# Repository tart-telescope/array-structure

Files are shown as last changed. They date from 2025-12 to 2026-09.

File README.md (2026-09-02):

# TART Array Structure

CAD files for the mechanical structure of the [TART (Transient Array Radio Telescope)](https://tart.elec.ac.nz/) antenna array — an open-source, low-cost radio telescope built from arrays of small antennas.

This repository contains the full set of design files needed to build the array structure: the master FreeCAD design, flat-pack cutting files (DXF) for CNC machining, 3D-printable parts (STL/3MF), and the FreeCAD source files for each component.

## Repository Layout

```
array-structure/
├── array-design.FCStd          # Master FreeCAD design of the spiral array structure
├── array-design.dxf            # 2D export of the array design
├── array-design.stp            # STEP (3D CAD exchange) export of the array design
├── spiral-array-screenshot.png # Render of the array
├── spiral-array-screenshot-2.png
├── brackets/                   # Brackets for mounting the array arms
├── cam-files/                  # CNC/laser/water-jet cutting files for plywood sheets
├── supports/                   # Stand support structures
└── truss_tube_support/         # Truss-tube support structure (3D-printable)
```

## cam-files/ — Plywood Cutting Files

Files for CNC cutting the flat-pack array structure from sheets of marine-grade exterior plywood. Each file is a full 2400 × 1200 mm sheet, and includes a marked 100 × 100 mm reference square for the workshop to calibrate dimensions against.

| File | Material |
|---|---|
| `tart_array_4mm_sheet_1.dxf` | Full sheet 2400 × 1200 mm, 4–6 mm plywood |
| `tart_array_4mm_sheet_2.dxf` | Full sheet 2400 × 1200 mm, 4–6 mm plywood |
| `tart_array_9mm.dxf` | Full sheet 2400 × 1200 mm, 9–12 mm plywood |

SVG versions are also provided. The sheets can be cut by laser or water-jet (both are unlikely to shift the material during cutting).

## brackets/ — Mounting Brackets

FreeCAD (`*.FCStd`) designs for the brackets that join the array components:

- `centre to post bracket.FCStd` — connects the array centre to the support post
- `post to arm bracket.FCStd` — connects the support post to the array arms
- `post to arm bracket-Post side bracket.3mf` — 3D-printable export of the post-side bracket

## supports/ — Stand Supports

- `StandFoot.FCStd` — stand foot designed for a 30 mm PVC pipe to serve as the stand leg.

## truss_tube_support/ — Truss Tube Support Structure

A truss-tube support structure design by **Shoaib Mirza** (shoaibmirza@iub.edu.bd), Independent University, Bangladesh, developed for the Bangladesh TART installation.

- `STLs/` — 16 3D-printable parts (STL, binary) covering the full assembly:

  | Group | Parts |
  |-------|-------|
  | Center Hub Assembly | `HUB-001` (top), `HUB-002` (middle), `HUB-003` (bottom) |
  | Joint Assembly | `JNT-001` base joint, `JNT-002`/`JNT-003` top joint parts A/B |
  | Stand Leg Assembly | `LEG-001`–`LEG-004` (parts A–D) |
  | Mount Assembly | `MNT-001` wing mount, `MNT-002`/`MNT-003` top secondary mount parts A/B |
  | Wing Assembly | `WNG-001` (top), `WNG-002` (middle), `WNG-003` (bottom) panels |

- `BOM_STL_Export.csv` — bill of materials listing every part, its assembly group, file name and format
- `full_assembly_step/truss_tube_tart.step` — full assembly as a STEP file
- `renders_and_drawings/START_stand_drawing_v4.pdf` — drawing of the stand

## Building Your Own Array

The DXF cutting files for the current array design live in the `cam-files/` directory (see the cam-files [README](cam-files/README.md) for details). All files in this repository are open — download, cut or print, and assemble.

## Videos

Build and installation guides on YouTube for the TART array structure:

| Video | Channel | What it covers |
|---|---|---|
| [The Structure of the TART Spiral Antenna Array](https://www.youtube.com/watch?v=TuFPHJMHvuQ) | TART Radio Telescope | How the spiral array is constructed from 3 layers of flat material, plus mounting it on site — the closest match to the `cam-files/` plywood sheets in this repo |
| [How to Build a Cheap Radio Telescope (TART Single Sheet)](https://www.youtube.com/watch?v=K_8zffsw-ng) | TART Radio Telescope | Full build of the simplest TART version from a single standard-size plywood sheet using off-the-shelf components |
| [Single Sheet Radio Telescope Antenna Array Construction](https://www.youtube.com/watch?v=15vWiKbK2I0) | Elec Research | How to make a simple single-sheet TART antenna array with easily available tools and materials |
| [Installing a Spiral TART Using Wooden Posts](https://www.youtube.com/watch?v=bsTKXGvduMo) | TART Radio Telescope | On-site installation: locating the posts that support each arm and making the final arm assembly — relevant to the `brackets/` and `supports/` designs |
| [Single Sheet TART Antenna Array Optimization](https://www.youtube.com/watch?v=b-6-I6850Wc) | Elec Research | Evolution of the antenna layout constrained to a single sheet of plywood — background on the `cam-files/` design |

More videos, including the "How to Build a Cheap Radio Telescope" series, are on the official [TART Radio Telescope YouTube channel](https://www.youtube.com/@TARTRadioTelescope).

## License / Credits

- Truss-tube support structure: Shoaib Mirza (Independent University, Bangladesh).
- See the `truss_tube_support/README.md` for details.

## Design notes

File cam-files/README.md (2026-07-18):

# Building your own array

There is a github repository (https://github.com/tart-telescope/array-structure) with DXF files for building the current antenna array design. The cam_files directory contains files to be CNC cut from sheets of marine grade experior plywood.

* [tart_array_4mm_sheet_1.dxf](https://github.com/tart-telescope/array-structure/blob/main/cam-files/tart_array_4mm_sheet_1.dxf). To be cut from a full sheet 2400x1200mm 4-6mm thickness plywood.
* [tart_array_4mm_sheet_2.dxf](https://github.com/tart-telescope/array-structure/blob/main/cam-files/tart_array_4mm_sheet_1.dxf). To be cut from a full sheet 2400x1200mm 4-6mm thickness plywood.
* [tart_array_9mm.dxf](https://github.com/tart-telescope/array-structure/blob/main/cam-files/tart_array_9mm.dxf). To be cut from a full sheet 2400x1200mm 9-12mm thickness plywood.

These three sheets can either be laser cut, or water-jet cut (these two options are unlikely to move during cutting). On each sheet is a 100mm x 100mm square (marked as such) that can be used as a reference for dimensions by the workshop doing the cutting.

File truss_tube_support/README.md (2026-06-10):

## Truss Tube Support Structure

By Shoaib Mirza (shoaibmirza@iub.edu.bd)

This beautiful design was developed by Shoaib Mirza of IUB Bangladesh for the Bangladesh TART installation.

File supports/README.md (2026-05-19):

## TART Array Supports

This file contains some standard support structures for the TART array.

### StandFoot

Designed for a 30mm PVC Pipe to act as stand feet.

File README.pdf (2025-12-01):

# TART Spiral Array Instructions to the Fabricator

This document contains instructions to help understand TART design and the DXF file provided with this document.

Written July 2025 – Theo Molteno (theo@elec.ac.nz)

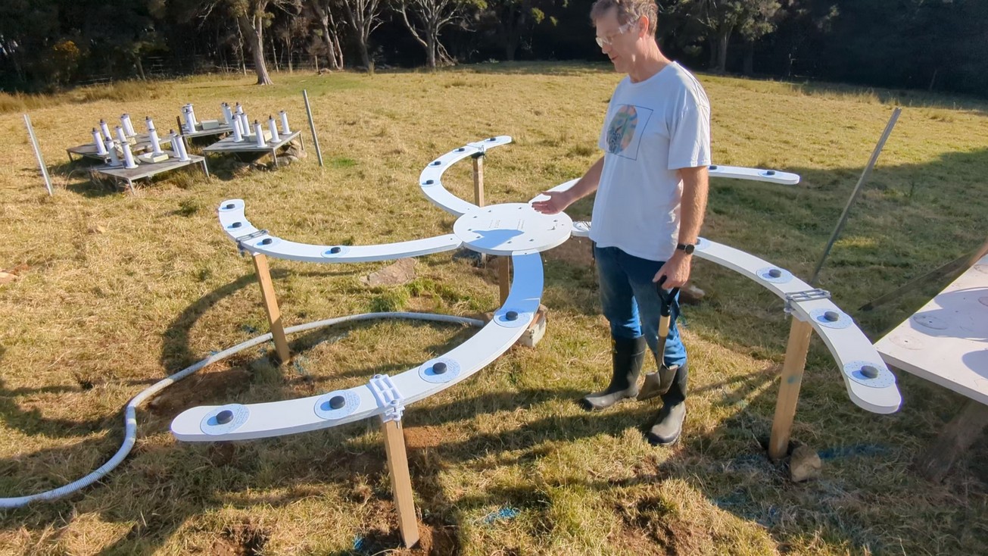
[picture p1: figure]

## TART design

This video explains the layer structure of the TART design:https://youtu.be/TuFPHJMHvuQ?si=yuicw4qd4V9sIJbK (https://youtu.be/TuFPHJMHvuQ?si=yuicw4qd4V9sIJbK)

Figure 1: The Spiral TART Array

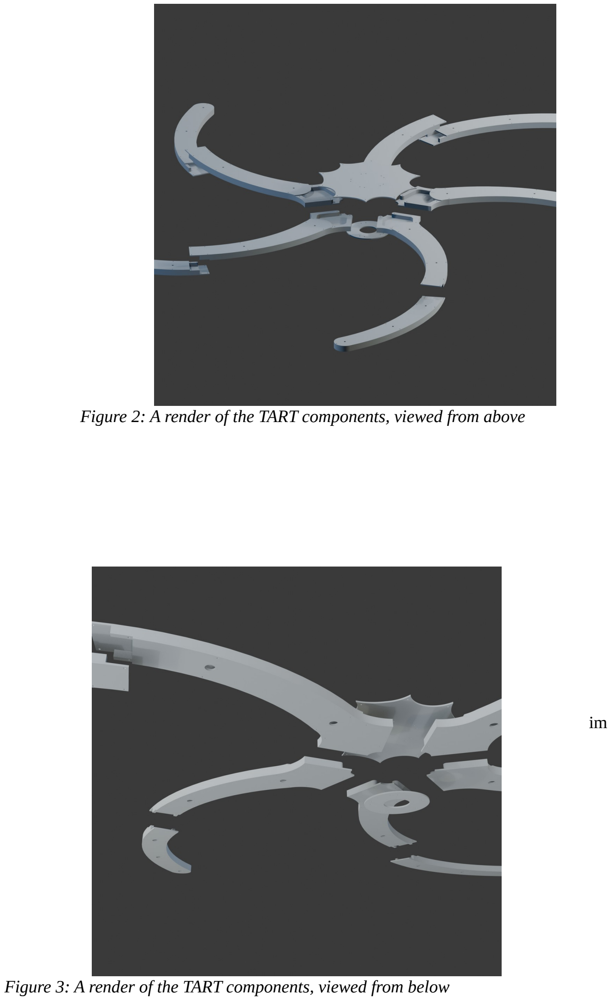
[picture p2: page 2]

im

Figure 2: A render of the TART components, viewed from above

Figure 3: A render of the TART components, viewed from below

## Annotated screenshot of assemblies

There are 4 separate types of parts to the TART labelled here.
1. Centre top (x1)
2. Inner Arm Assembly (x5)
3. Outer Arm Assembly (x5)
4. Centre bottom, which is just a ring with bolt holes in it (x1)
Each one of these assemblies is bolted together in the final array, but is glued and dowelled together proir to installation form multiple pieces of the plywood.

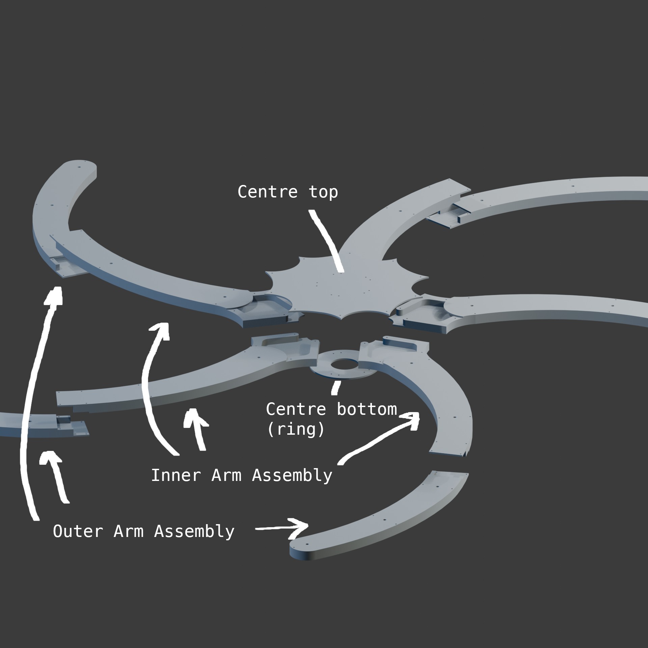
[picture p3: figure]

## DXF file

This is what the DXF file looks like. It’s arranged so that the different groups of parts are easy to see (see colour coded groups below)

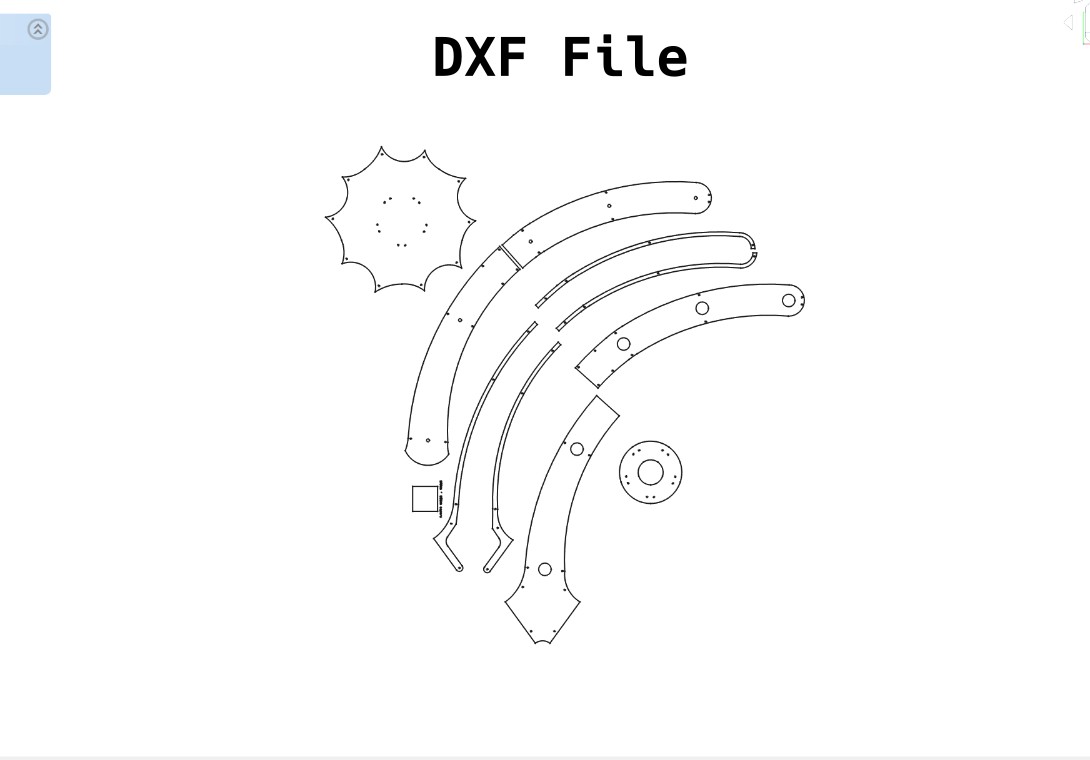
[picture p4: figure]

In the following chart you can see each assembly colour coded together.

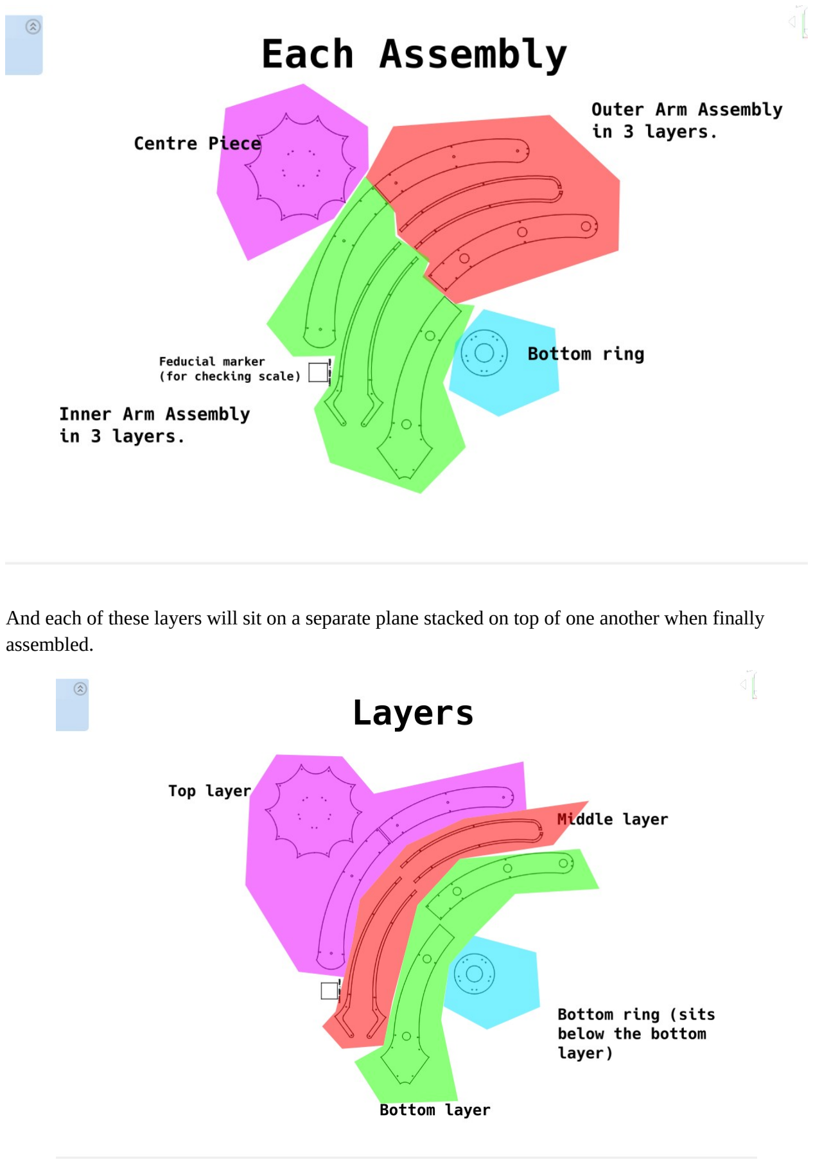
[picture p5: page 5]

And each of these layers will sit on a separate plane stacked on top of one another when finally assembled.

Each of the assemblies is glued and dowelled together. To construct the final TART, the assemblies are bolted together. The bolt holes and dowel holes are both exactly 6mm in the design, and should be cut as such.
The following chart shows which 6mm holes are dowel holes and which are bolt holes.

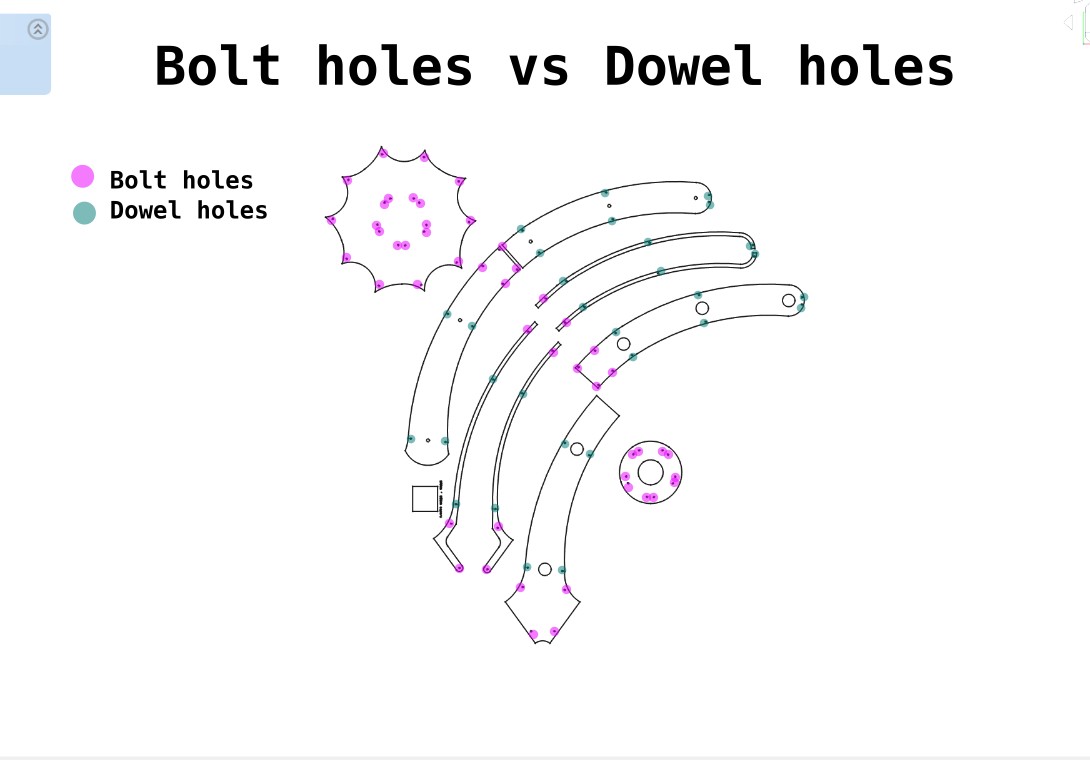
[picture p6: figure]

NOTE on cutting the DXF: try to cut each of the 6mm holes to that dimension exactly if possible to make sure the dowels and bolts fit snugly. On a laser cutter this may involve using a kerf distance of half the laser width on these lines. How all the rest of the lines are cut is less important, but should be consistent so that the layers all line up with one another.
NOTE on Layer thickness. For our prototype we have been using 6mm plywood for the top, bottom, and bottom ring constructions, and two stacked 9mm plywood (18mm effective thickness) for the middle layer. The middle layer needs this thickness for cable routing and enough space for underneath the antennas. The top layer especially can’t be particularly thick otherwise the antennas won’t screw on properly. We reccomend 6mm for this.

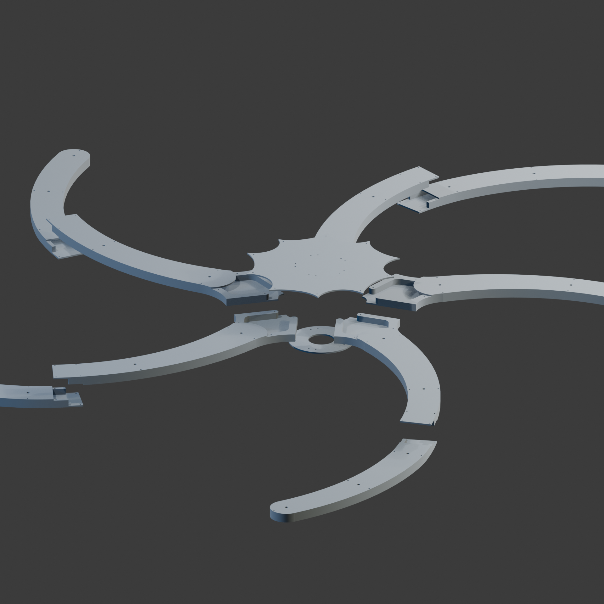
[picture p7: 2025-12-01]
spiral-array-screenshot.png

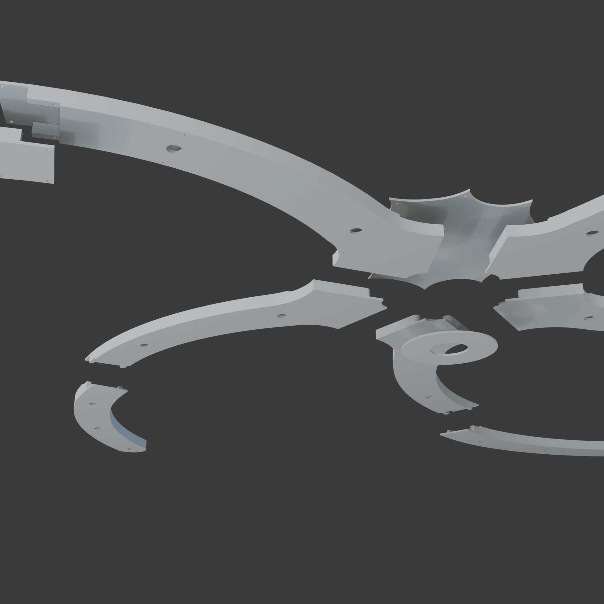
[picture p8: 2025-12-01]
spiral-array-screenshot-2.png

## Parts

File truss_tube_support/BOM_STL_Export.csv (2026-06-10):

Part Number | Assembly Group | Description | File Name | Format | Mesh Refinement | Notes
HUB-001 | Center Hub Assembly | Center Hub Top | HUB-001_Center-Hub-Top.stl | STL (Binary) | Medium
HUB-002 | Center Hub Assembly | Center Hub Middle | HUB-002_Center-Hub-Middle.stl | STL (Binary) | Medium
HUB-003 | Center Hub Assembly | Center Hub Bottom | HUB-003_Center-Hub-Bottom.stl | STL (Binary) | Medium
JNT-001 | Joint Assembly | Base Joint | JNT-001_Base-Joint.stl | STL (Binary) | Medium
JNT-002 | Joint Assembly | Top Joint Part A | JNT-002_Top-Joint_Part-A.stl | STL (Binary) | Medium
JNT-003 | Joint Assembly | Top Joint Part B | JNT-003_Top-Joint_Part-B.stl | STL (Binary) | Medium
LEG-001 | Stand Leg Assembly | Stand Leg Part A | LEG-001_Stand-Leg_Part-A.stl | STL (Binary) | Medium
LEG-002 | Stand Leg Assembly | Stand Leg Part B | LEG-002_Stand-Leg_Part-B.stl | STL (Binary) | Medium
LEG-003 | Stand Leg Assembly | Stand Leg Part C | LEG-003_Stand-Leg_Part-C.stl | STL (Binary) | Medium
LEG-004 | Stand Leg Assembly | Stand Leg Part D | LEG-004_Stand-Leg_Part-D.stl | STL (Binary) | Medium
MNT-001 | Mount Assembly | Wing Mount | MNT-001_Wing-Mount.stl | STL (Binary) | Medium
MNT-002 | Mount Assembly | Top Secondary Mount Part A | MNT-002_Top-Secondary-Mount_Part-A.stl | STL (Binary) | Medium
MNT-003 | Mount Assembly | Top Secondary Mount Part B | MNT-003_Top-Secondary-Mount_Part-B.stl | STL (Binary) | Medium
WNG-001 | Wing Assembly | Wing Top Panel | WNG-001_Wing-Top-Panel.stl | STL (Binary) | Medium
WNG-002 | Wing Assembly | Wing Middle Panel | WNG-002_Wing-Middle-Panel.stl | STL (Binary) | Medium
WNG-003 | Wing Assembly | Wing Bottom Panel | WNG-003_Wing-Bottom-Panel.stl | STL (Binary) | Medium

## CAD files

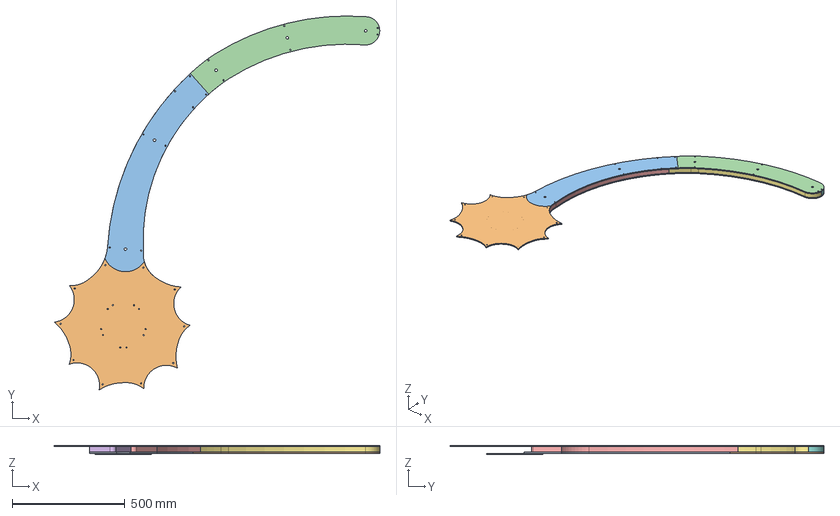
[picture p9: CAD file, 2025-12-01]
array-design.stp
1442.1 x 1656.5 x 42.0 mm
bottom cap
Centre top
upper arm top
lower arm top
upper arm wall small
upper arm wall big
lower inner arm wall
lower outer arm wall
upper arm bottom
lower arm bottom

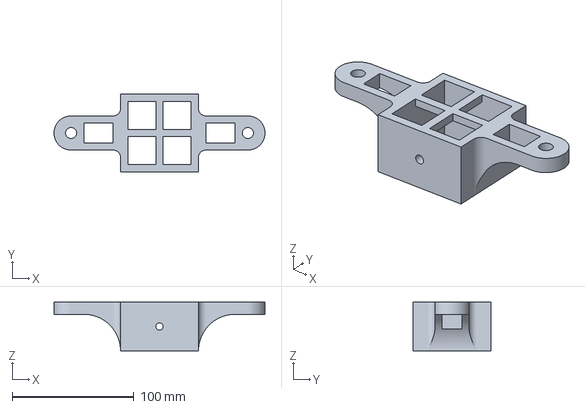
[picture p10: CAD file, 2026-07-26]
brackets/post to arm bracket-Post side bracket.3mf
173.0 x 64.0 x 40.0 mm

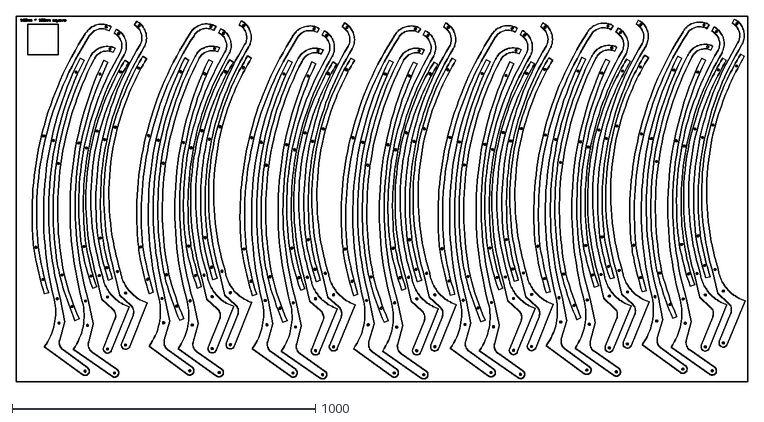
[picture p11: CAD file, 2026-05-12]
cam-files/tart_array_9mm.dxf
2413.0 x 1206.5

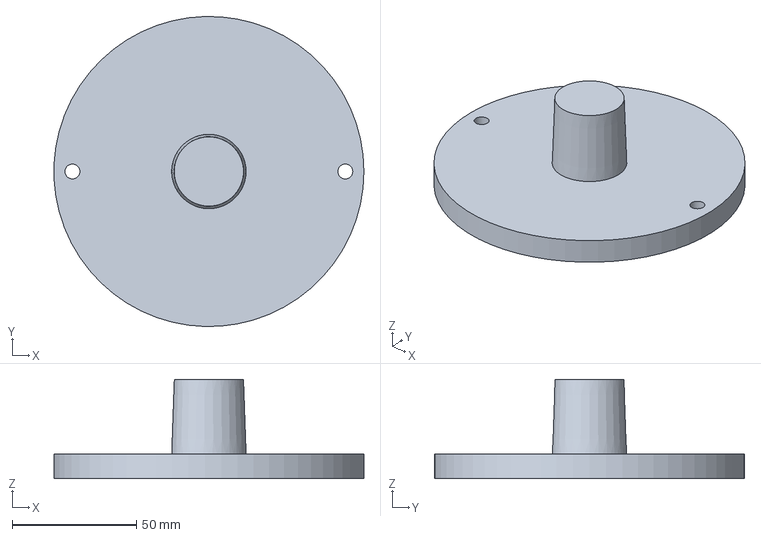
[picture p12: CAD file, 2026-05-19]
supports/StandFoot.FCStd
124.9 x 125.0 x 40.0 mm

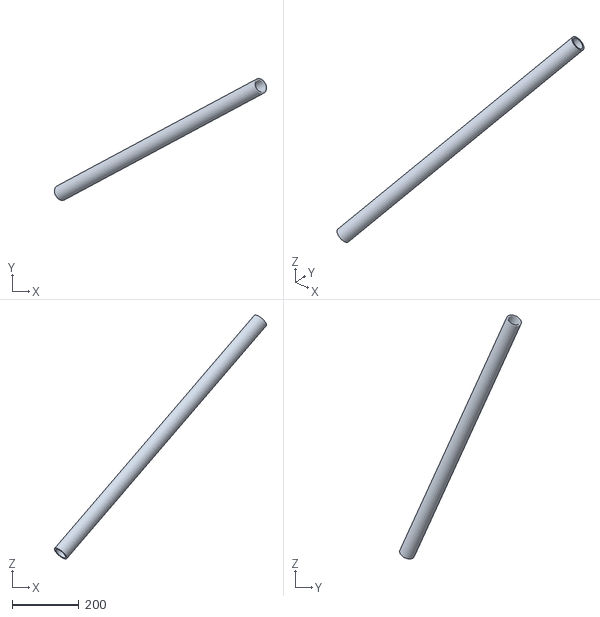
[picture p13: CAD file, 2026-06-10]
truss_tube_support/STLs/LEG-001_Stand-Leg_Part-A.stl
635.2 x 364.7 x 730.4

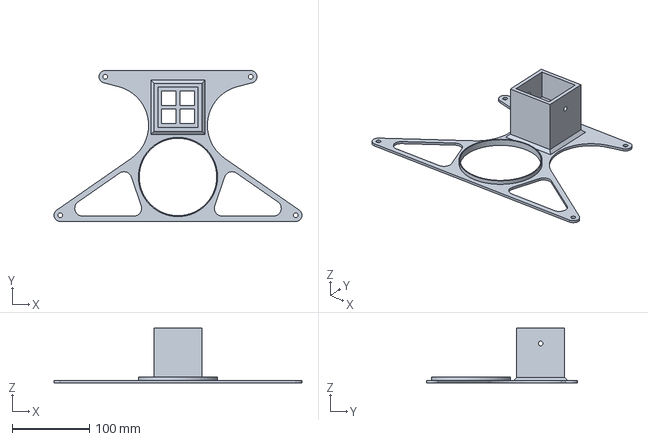
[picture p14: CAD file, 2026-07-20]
brackets/centre to post bracket.FCStd
320.3 x 194.9 x 71.0 mm

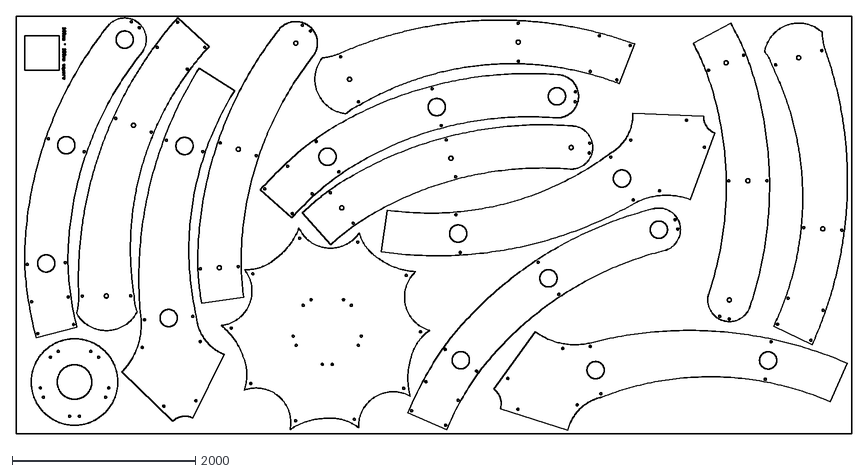
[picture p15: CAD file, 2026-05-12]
cam-files/tart_array_4mm_sheet_1.dxf
9120.0 x 4560.0

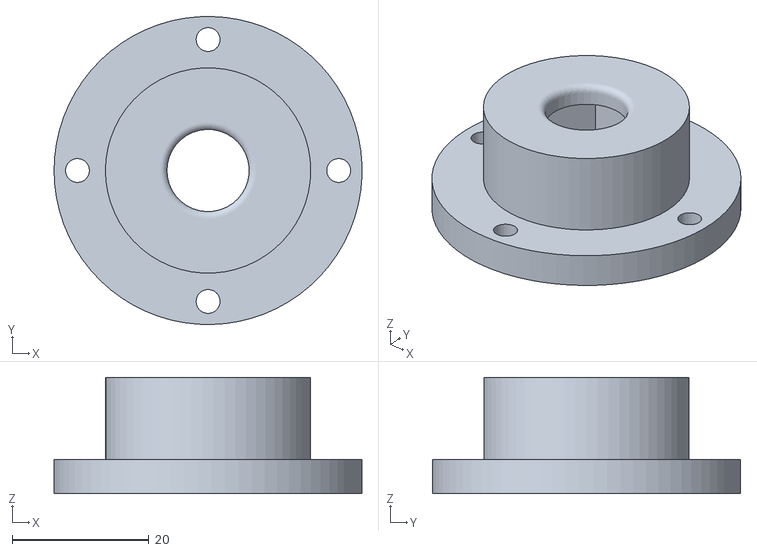
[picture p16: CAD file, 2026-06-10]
truss_tube_support/STLs/MNT-001_Wing-Mount.stl
45.0 x 45.0 x 17.0

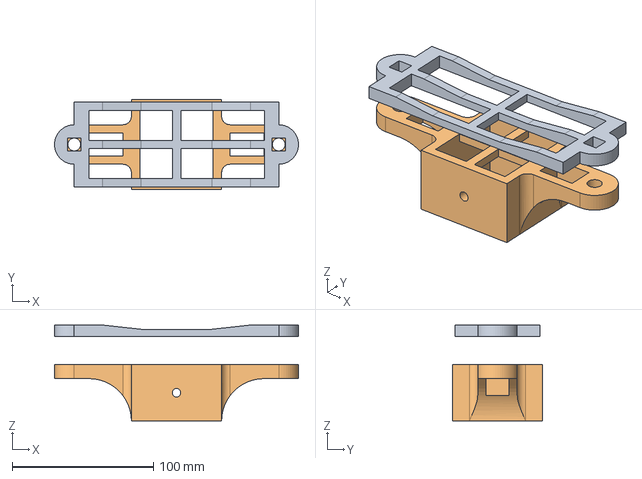
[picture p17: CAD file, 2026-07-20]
brackets/post to arm bracket.FCStd
173.0 x 64.0 x 68.0 mm
arm side bracket
Post side bracket

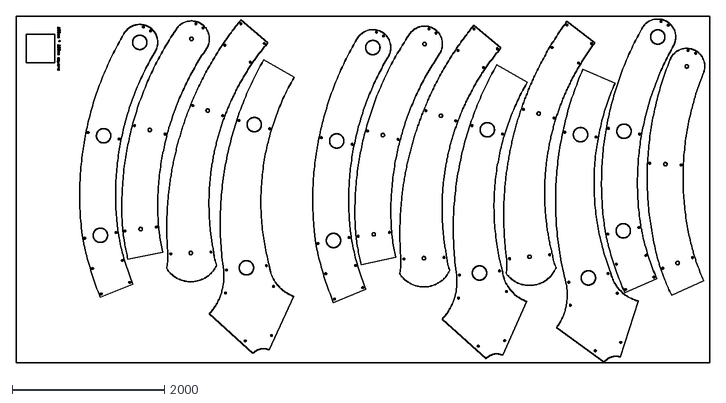
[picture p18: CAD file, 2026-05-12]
cam-files/tart_array_4mm_sheet_2.dxf
9120.0 x 4560.0

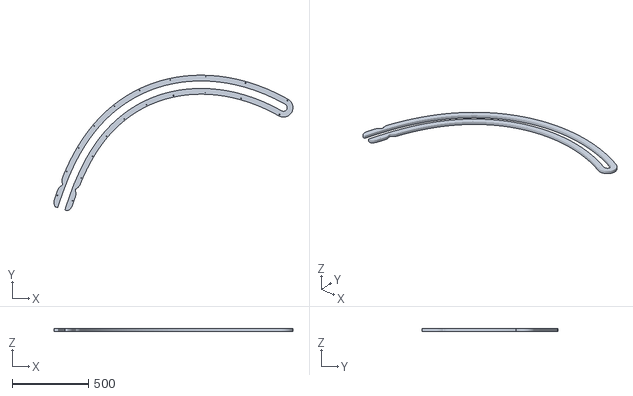
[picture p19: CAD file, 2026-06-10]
truss_tube_support/STLs/WNG-002_Wing-Middle-Panel.stl
1570.7 x 891.4 x 18.8

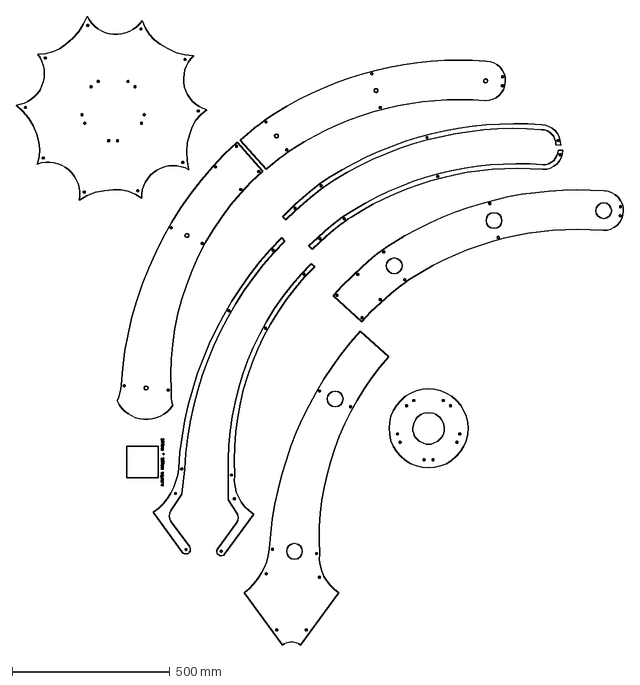
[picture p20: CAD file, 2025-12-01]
cam-files/D Spiky centre single arm - split outer arm 2.dxf
1922.7 x 1991.1 mm

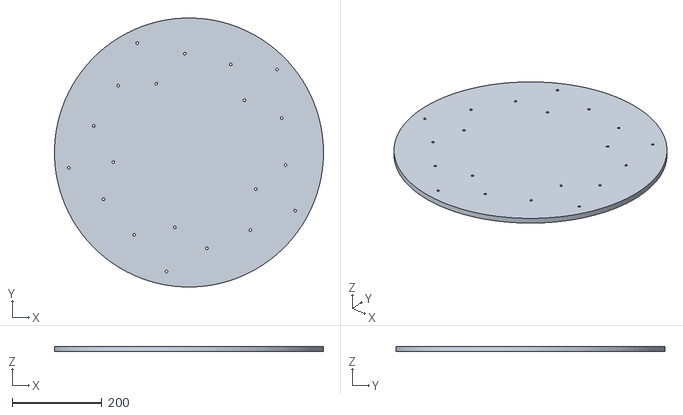
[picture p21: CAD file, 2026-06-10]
truss_tube_support/STLs/HUB-001_Center-Hub-Top.stl
599.9 x 599.9 x 12.0

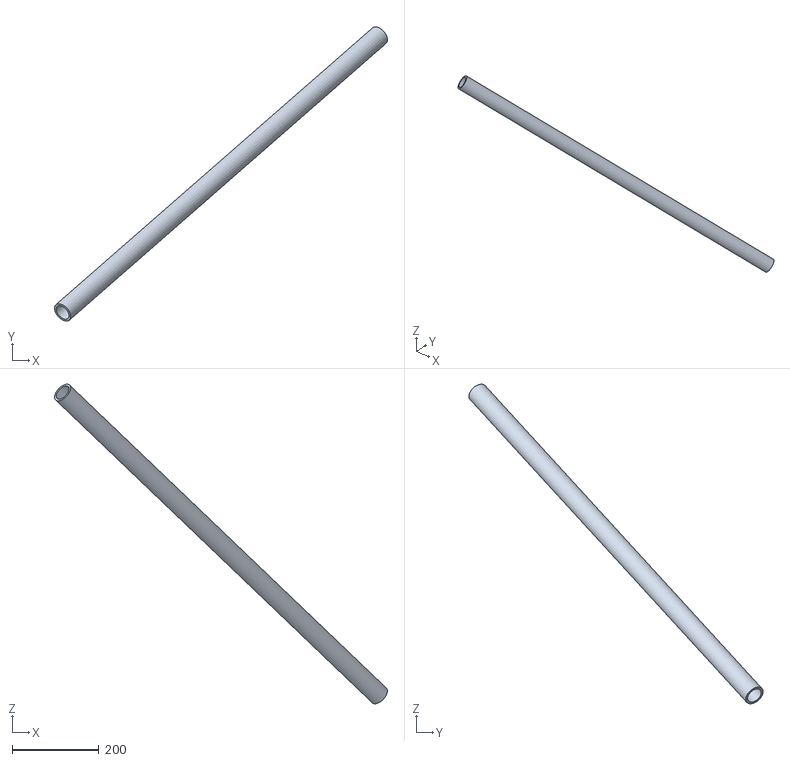
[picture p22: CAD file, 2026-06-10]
truss_tube_support/STLs/LEG-002_Stand-Leg_Part-B.stl
767.6 x 678.3 x 736.6

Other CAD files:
truss_tube_support/STLs/LEG-003_Stand-Leg_Part-C.stl
truss_tube_support/STLs/JNT-001_Base-Joint.stl
truss_tube_support/STLs/MNT-002_Top-Secondary-Mount_Part-A.stl
truss_tube_support/STLs/WNG-001_Wing-Top-Panel.stl
array-design.FCStd
truss_tube_support/STLs/HUB-002_Center-Hub-Middle.stl
truss_tube_support/STLs/HUB-003_Center-Hub-Bottom.stl
truss_tube_support/STLs/JNT-002_Top-Joint_Part-A.stl
truss_tube_support/STLs/JNT-003_Top-Joint_Part-B.stl
truss_tube_support/STLs/LEG-004_Stand-Leg_Part-D.stl
truss_tube_support/STLs/MNT-003_Top-Secondary-Mount_Part-B.stl
truss_tube_support/STLs/WNG-003_Wing-Bottom-Panel.stl

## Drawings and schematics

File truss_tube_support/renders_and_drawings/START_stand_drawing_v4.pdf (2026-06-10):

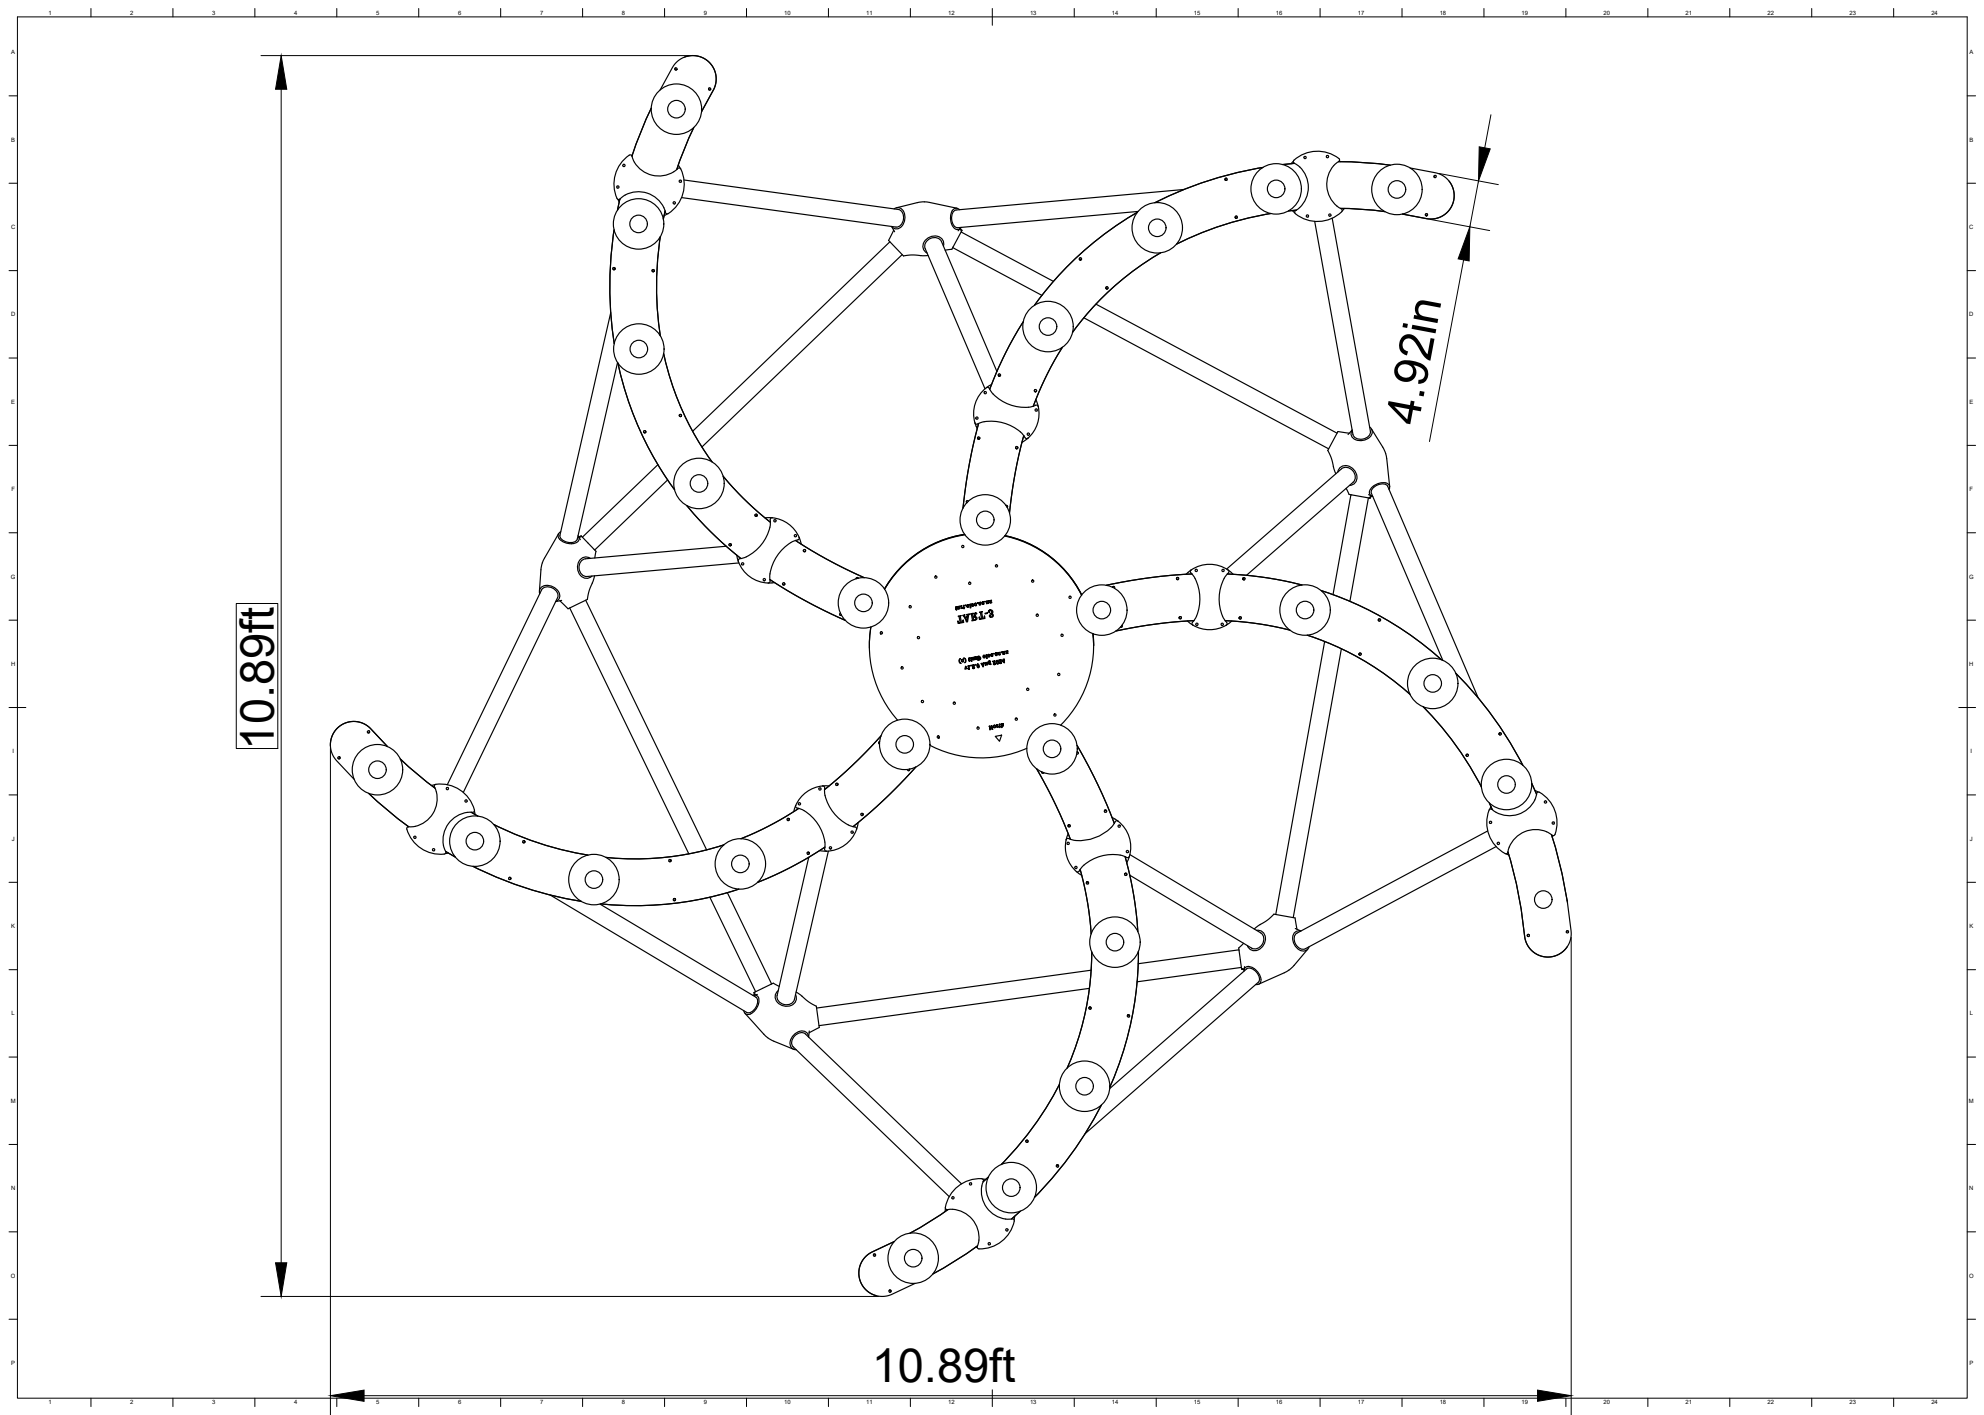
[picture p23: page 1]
10.89ft 1 2 3 4 5 6 7 8 9 10 11 12 13 14 15 16 17 18 19 20 21 22 23 24 1 2 3 4 5 6 7 8 9 10 11 12 13 14 15 16 17 18 19 20 21 22 23 24 BADCFEHGIKJMLONP BADCFEHGIKJMLONP 4.92in

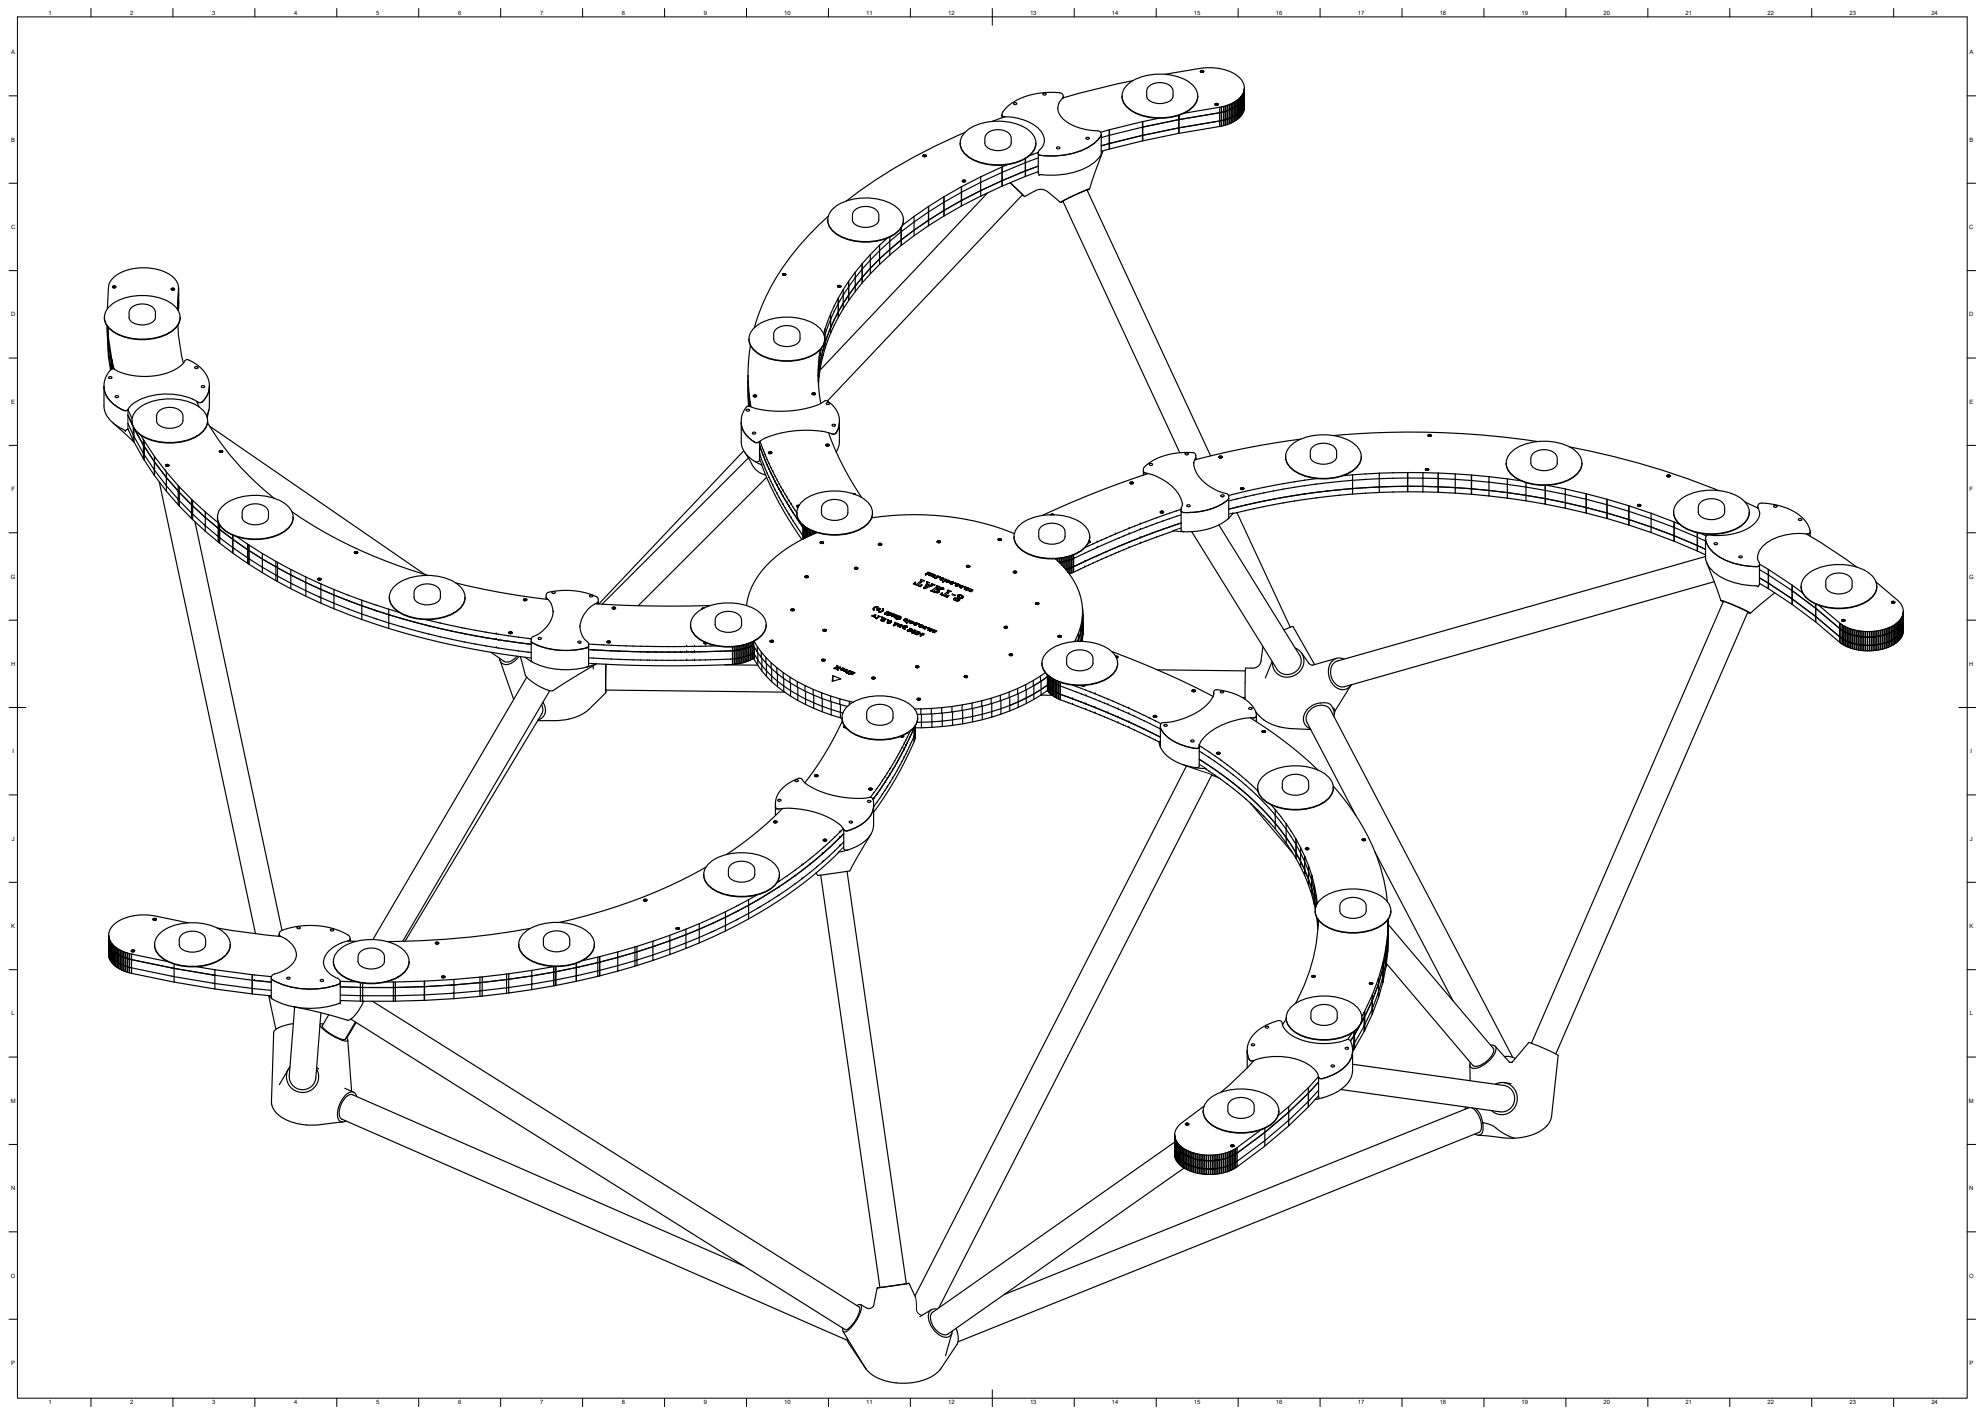
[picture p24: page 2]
24 BADCFEHGIKJMLONP; BADCFEHGIKJMLONP

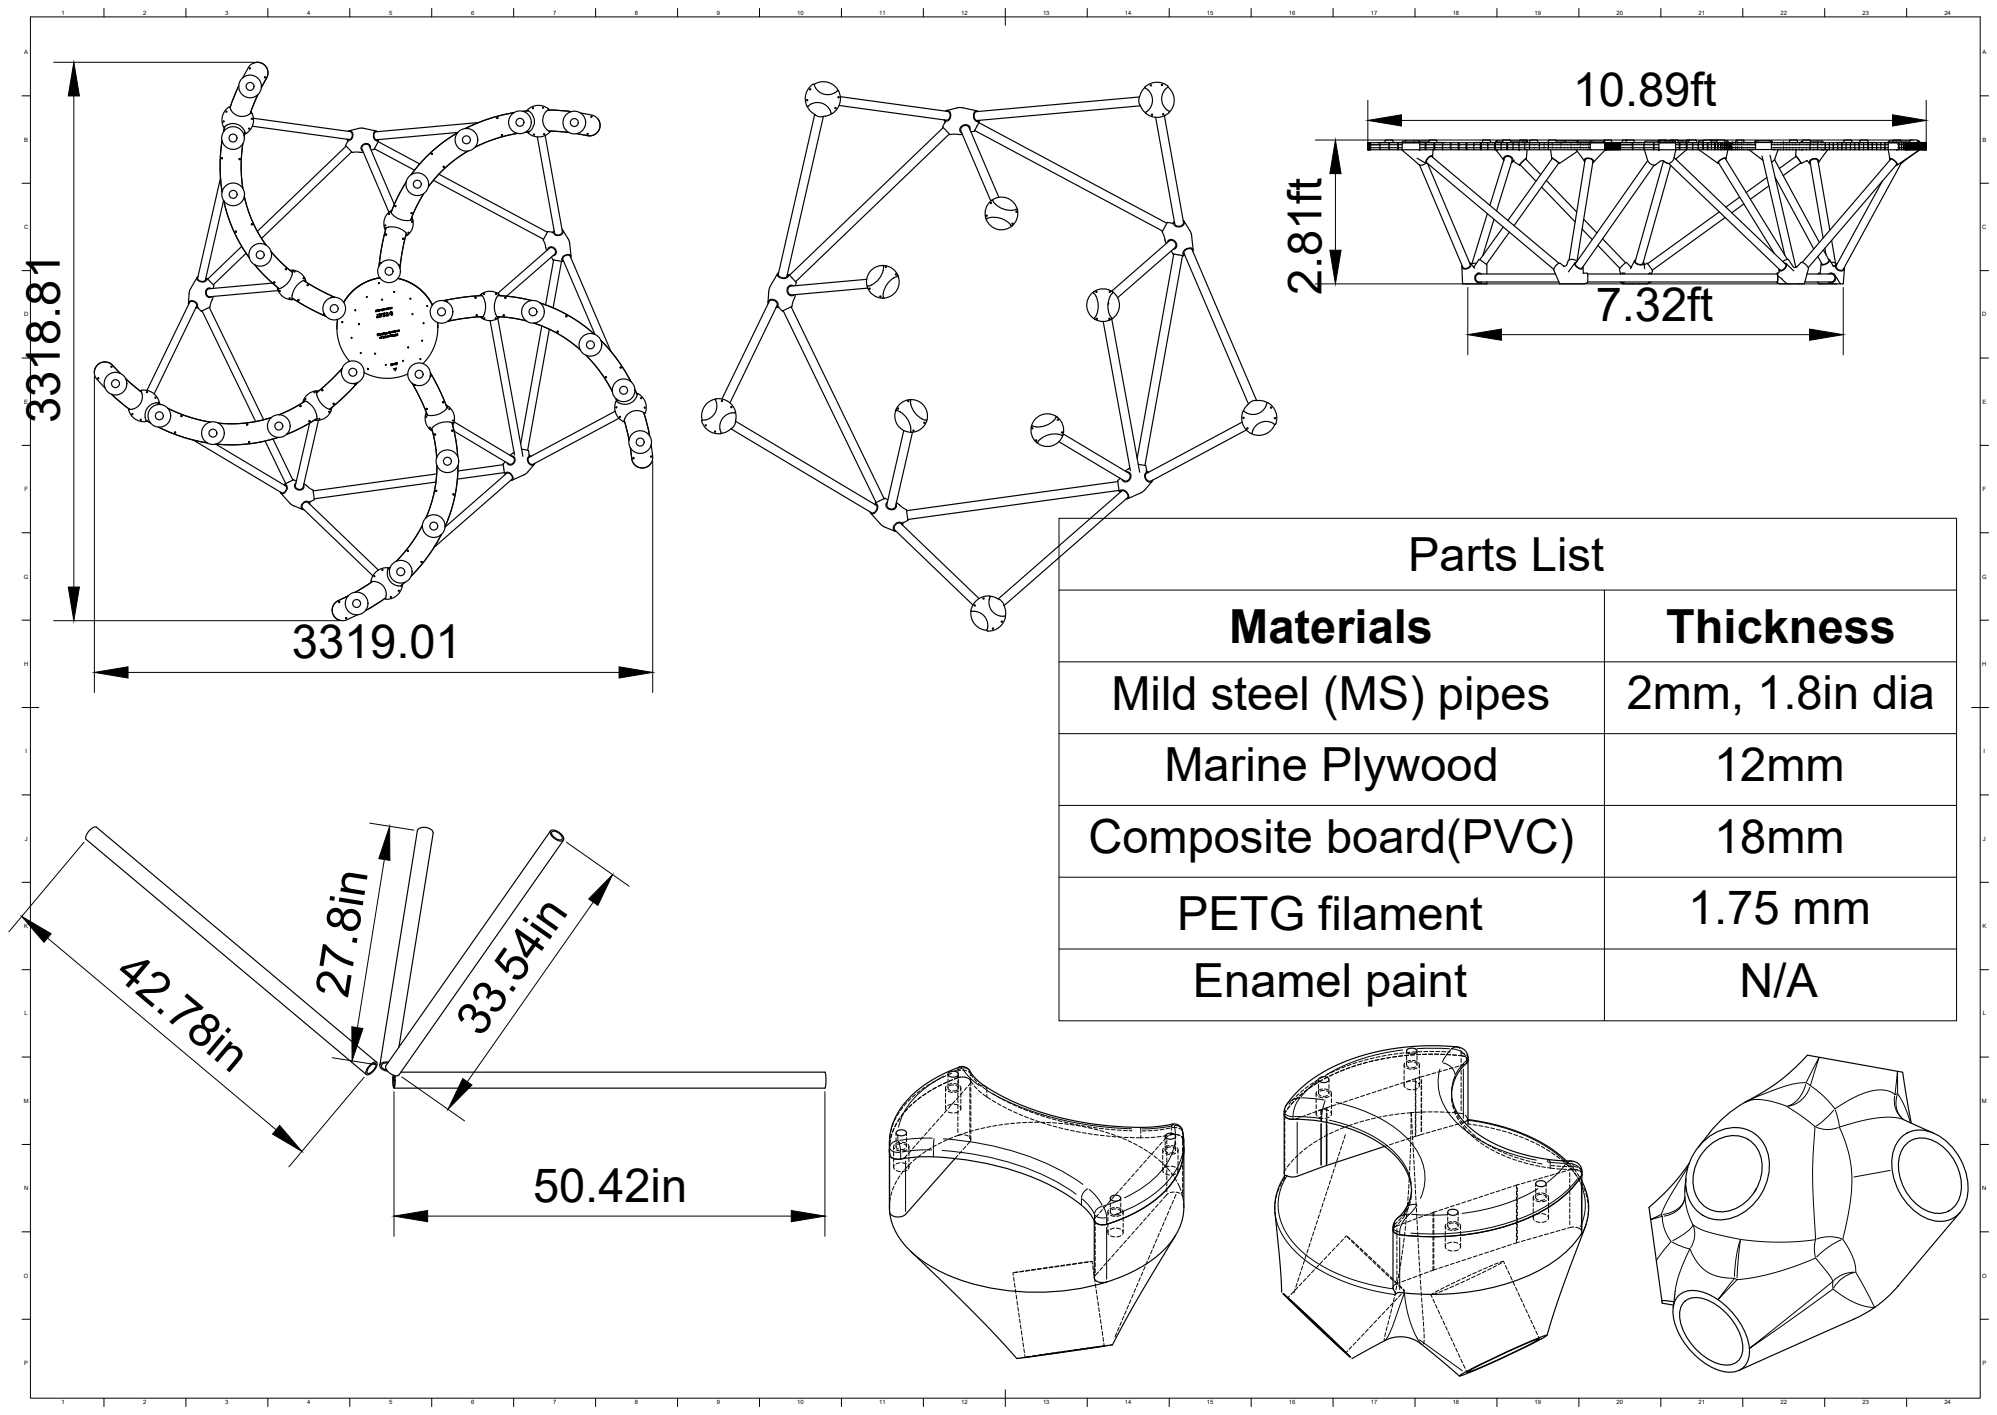
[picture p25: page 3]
24 BADCFEHGIKJMLONP; BADCFEHGIKJMLONP 10.89ft

42.78in 50.42in 33.54in 27.8in Parts List Materials Thickness Mild steel (MS) pipes 2mm, 1.8in dia Marine Plywood 12mm Composite board(PVC) 18mm PETG filament 1.75 mm Enamel paint N/A

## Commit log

2026-05-12 Added dxf files
    [D Spiky centre single arm - split outer arm 2.dxf, tart_array_4mm_sheet_1.dxf, tart_array_4mm_sheet_2.dxf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]
2026-05-19 Added some stand supports
    [StandFoot.FCStd]
2026-05-19 Rename array -> cam-files
    [D Spiky centre single arm - split outer arm 2.dxf, tart_array_4mm_sheet_1.dxf, tart_array_4mm_sheet_2.dxf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]
2026-06-10 Added truss tube support
    [BOM_STL_Export.csv, HUB-001_Center-Hub-Top.stl, HUB-002_Center-Hub-Middle.stl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]
2026-07-20 Add brackets
    [centre to post bracket.FCStd, post to arm bracket.FCStd]
2026-07-26 Added new bracket
    [post to arm bracket-Post side bracket.3mf]
